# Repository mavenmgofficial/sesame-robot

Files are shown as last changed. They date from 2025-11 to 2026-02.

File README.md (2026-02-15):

# The Sesame Robot Project 
___







sesame-cover

___

**Greetings, from your new best friend.**

Sesame is an accessible Open-Source robotics project based on the ESP32 microcontroller system, with an emphasis on expression and movement. 
This project is designed for makers and engineers of all skill levels! Sesame offers a dynamic platform designed to start working with walking robots. 
To build a sesame robot, you will need basic soldering skills, $50-60 in hardware components, access to a 3D printer, and a basic understanding of Arduino IDE.

This repository contains the CAD design files, STL files, build and wiring guides, and the base/expanded firmware for the ESP32-based controller. 
There is also some included debugging firmware that may be helpful in getting your Sesame up and running.

## Features

*   **Quadruped Design:** Uses 8 servo motors (2 per leg) to achieve roughly 8 total degrees of freedom.
*   **Emotive Display:** Features a 128x64 OLED screen acting as a reactive face that syncs with movement.
*   **Fully Printable:** Designed entirely for 3D printing in PLA with minimal supports.
*   **Network Connectivity:** Connect to your WiFi network for remote control and API access.
*   **JSON API:** RESTful API for programmatic control from Python, JavaScript, and more.
*   **Conversational Faces:** Expressive emotion library with talk variants for voice assistant projects.
*   **Sesame Studio:** New animation composer software to easily create custom movements.
*   **Sesame Companion App:** Python application for voice control and advanced interactions.
*   **Serial CLI:** Control the robot and trigger animations via a Serial Command Line Interface or the web UI.
*   **Pre-programmed Emotes:** Includes animations for Walking, Waving, Dancing, Pointing, Resting, and more.

## Watch the launch video on YouTube

<a href="https://www.youtube.com/watch?v=1UDsWkcQZhc">thumb-youtube</a>

___

## Getting Started

Follow these steps to build your own Sesame Robot:

### 1. Gather Parts 
Check the **[Bill of Materials (BOM)](hardware/bom/README.md)** for a complete list of required electronics and hardware.
*   Microcontroller: Lolin S2 Mini (recommended for new builds) or ESP32-DevKitC-32E with Distro Board V1
*   Actuators: 8x MG90 Servos
*   Power: 5V 3A source (USB-C PD for S2 Mini or battery + buck for both; see BOM for the 2× 10440 Li-ion + 2× AAA holder option)

### 2. Print Parts 
Download the STLs and follow the **[Printing Guide](hardware/printing/README.md)**.
*   Designed for PLA
*   Minimal supports required

### 3. Build & Wire 
Follow the **[Build Guide](docs/build-guide/README.md)** and **[Wiring Guide](docs/wiring-guide/README.md)** to assemble the frame and connect the electronics.

### 4. Flash Firmware 
Upload the code from the **[Firmware Directory](firmware/README.md)**.
*   Requires Arduino IDE
*   Configure WiFi AP settings

### 5. Create Animations 
Use **[Sesame Studio](software/sesame-studio/README.md)** to visually design poses and sequences for your robot.

sesame-wakeup-gif

---

## Software & Firmware

### Sesame Studio
Sesame Studio is a standalone desktop application included in `software/sesame-studio/`. It allows you to:
*   Visually pose the robot using a schematic interface.
*   Generate C++ code for servo angles automatically.
*   Sequence frames into complex animations.

[**> Go to Sesame Studio**](software/sesame-studio/README.md)

sesamestudio-preview

### Sesame Companion App
The Sesame Companion App is a Python-based application that enables advanced control and interaction with your robot over your local network. It leverages the new JSON API and network mode features to provide:
*   **Voice Assistant Integration:** Control Sesame with voice commands and see real-time emotional expressions.
*   **Remote Control:** Command your robot from anywhere on your local network.
*   **Face Control:** Change expressions dynamically based on conversation or context.
*   **API Examples:** Reference implementation for building your own integrations.

The Companion App works with robots running the latest firmware with network mode enabled.

[**> Go to Sesame Companion App Repository**](https://github.com/dorianborian/sesame-companion-app)

### Firmware
The ESP32 firmware (`sesame-firmware-main.ino`) handles the kinematics, face display, and WiFi control interface.
*   **Web UI:** Control the robot from your phone via the built-in Access Point.
*   **Custom Faces:** Add your own bitmaps (guide in firmware docs).

[**> Go to Firmware Docs**](firmware/README.md)

firmware-preview

---

## Contributing

This robot is a platform for building new features, cosmetics, tools, and ideas. Since the current firmware is a basic implementation, pull requests are very welcome for:
*   Kinematics improvements
*   New animations
*   Improved Web UI/UX
*   Sensor integration (Ultrasonic, Gyro, etc.)

I would also love to see forks of this project with new hardware, software, faces, etc. Be sure to send me a message if you end up building one, and I might feature you on my website or channel!
  
---

## Sesame Complete Build Kit Pre-orders available!
I am excited to announce that, after popular demand, Sesame Complete Build Kits are now available for pre-order! 

That's right, your little robot companion just got even easier to build. Each kit includes all the components you need to build a full Sesame Robot. With the included detailed instructions, guides, and resources, this kit is perfect for both seasoned Makers and beginners. Click the image below to learn more.

<a href="https://www.doriantodd.com/sesame/kit">kits-availible</a>

---

*Created by [Dorian Todd](https://www.doriantodd.com/). Need help with your Sesame Robot? Send me a message on Discord, my username is "starphee"*

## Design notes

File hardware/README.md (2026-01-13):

# Hardware

All mechanical and electrical source files for the Sesame Robot live here. The hardware stack supports two build paths:

- **Hand-wired / S2 Mini build** for simple protoboard construction.
- **Custom Sesame Distro Board build** for a cleaner ESP32-DevKitC-32E stackup.

Use the sections below to jump to the files that match the version you are assembling.

## Directory Guide

| Folder | What you will find |
| --- | --- |
| [bom](bom/README.md) | Full bill of materials covering both wiring approaches, plus power budget notes and links back to the build tutorial. Start here to gather every component before printing or soldering. |
| [cad](cad/README.md) | Parametric STEP and Fusion 360 source models for every printed part. Great for remixing joint geometry or adapting the shell—just note the caution about features that may not translate across CAD packages. |
| [pcb](pcb/README.md) | Sesame Distro Board schematics, layout renders, and the `Gerber_Sesame-Distro-Board_PCB_Sesame-Distro-Board_V1.zip` archive you can upload to PCBway (ordering steps included). |
| [printing](printing/README.md) | Practical PLA print settings, support callouts, and image references for joint orientation and the top cover’s manual supports. |

## Getting Started

1. **Decide on a wiring strategy.** Review the comparison section in [docs/wiring-guide/README.md](../docs/wiring-guide/README.md) to choose between the protoboard and custom PCB routes.
2. **Print the shell and joints.** Follow the presets in [printing/README.md](printing/README.md) to prep the 3D files from `hardware/printing/stl`.
3. **Source electronics.** Use the line-by-line list in [bom/README.md](bom/README.md) and verify your power supply meets the 5V/3A requirement.
4. **Assemble electronics.** Reference either the hand-wiring steps or the distro-board guide plus the wiring diagrams in `docs/wiring-guide/`.

> [!TIP]
> Keep photos of your wiring progress. They are invaluable for troubleshooting later and help when sharing build notes with the community.

## Supporting Documents

- [docs/build-guide/README.md](../docs/build-guide/README.md) for end-to-end assembly sequencing.
- [docs/wiring-guide/README.md](../docs/wiring-guide/README.md) for wiring diagrams, safety notes, and packing tips.

Improvements, remixes, and test reports are welcome, file issues or PRs with any updates you discover while building. <3

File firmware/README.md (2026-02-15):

# Sesame Robot Firmware

This document provides technical information on the firmware architecture, control logic, and hardware abstraction layers used in the Sesame Robot.

>[!NOTE]
> The firmware is now organized into a modular structure with a main entry point and specialized header files for bitmaps, movement, and web assets. This makes customization much easier and the codebase cleaner.

## Table of Contents

- [How to Flash the Firmware](#how-to-flash-the-firmware)
- [Network Configuration](#network-configuration--connectivity)
- [API Reference](#api-reference)
  - [Legacy Web Endpoints](#legacy-web-endpoints)
  - [JSON API](#json-api-recommended-for-network-clients)
  - [Python Examples](#python-api-example)
  - [JavaScript Examples](#nodejsjavascript-example)
- [Advanced Integration Examples](#advanced-integration-examples)
  - [Voice Assistant Integration](#voice-assistant-integration)
  - [Home Automation](#home-automation-integration)
- [Idle Animation System](#idle-animation-system)
- [Firmware Architecture](#firmware-architecture)
- [Technical Implementation](#technical-implementation-overview)
- [Asset Pipeline & Face Customization](#asset-pipeline--face-customization)
- [Hardware Abstraction Layer](#hardware-abstraction-layer-hal)

## How to Flash the Firmware

### Prerequisites
1. **Arduino IDE** (version 2.0 or higher recommended)
2. **ESP32 Board Support**: Install via Arduino IDE's Board Manager
   - Open Arduino IDE
   - Go to **File → Preferences**
   - Add to "Additional Board Manager URLs": `https://raw.githubusercontent.com/espressif/arduino-esp32/gh-pages/package_esp32_index.json`
   - Go to **Tools → Board → Boards Manager**
   - Search for "ESP32" and install "ESP32 by Espressif Systems" (v2.0.0 or higher)
3. **Required Libraries** (install via Library Manager):
   - `ESP32Servo`
   - `Adafruit SSD1306`
   - `Adafruit GFX Library`

### Flashing Steps
1. **Connect your board** via USB to your computer
2. **Open the firmware**:
   - Open [sesame-firmware-main.ino](sesame-firmware-main.ino) in Arduino IDE
   - Make sure you have it in a folder with the same name.
   - Also include all of the .h header files.
3. **Select your board**:
   - Go to **Tools → Board**
   - For Lolin S2 Mini: Select "LOLIN S2 Mini"
   - For Sesame Distro Board V1: Select "ESP32 Dev Module"
4. **Configure board settings** (if using Lolin S2 Mini):
   - **Upload Speed**: 921600
   - **USB CDC On Boot**: "Enabled"
   - **Partition Scheme**: "Default 4MB with spiffs"
5. **Select the correct port**:
   - Go to **Tools → Port** and select your ESP32's COM port
6. **Choose your board configuration** in the code:
   - Open [sesame-firmware-main.ino](sesame-firmware-main.ino)
   - Find the pin configuration section (around line 55-65)
   - **If you built with the Lolin S2 Mini:** Uncomment the S2 Mini `servoPins` array and `I2C_SDA`/`I2C_SCL` defines. Comment out the Distro Board section.
   - **If you built with the Distro Board V1 and ESP32-DevKitC-32E:** Uncomment the Distro Board `servoPins` array and `I2C_SDA`/`I2C_SCL` defines. Comment out the S2 Mini section.
7. **(Optional) Configure network mode**:
   - If you want the robot to connect to your WiFi network (for API access and remote control), edit the network configuration section (around line 17-22):
   ```cpp
   #define NETWORK_SSID "YourNetworkName"  // Your WiFi network name
   #define NETWORK_PASS "YourPassword"     // Your WiFi password
   #define ENABLE_NETWORK_MODE true        // Set to true to enable
   ```
   - Leave `ENABLE_NETWORK_MODE false` to use Access Point mode only
8. **Upload the firmware**:
   - Click the **Upload** button (→) in Arduino IDE
   - Wait for compilation and upload to complete
9. **Test the connection**:
   - Open Serial Monitor (**Tools → Serial Monitor**, set baud rate to 115200)
   - Reset the board - you should see startup messages and network information
   - The serial monitor provides individual motor control for testing and troubleshooting
   - **If using AP mode only**: Connect to the "Sesame-Controller-BETA" WiFi network (password: `12345678`) and navigate to any website
   - **If using network mode**: Look for the "Connected to network!" message in Serial Monitor, then access via `http://sesame-robot.local` or the displayed IP address

### Troubleshooting
- **Upload fails**: Try holding the BOOT button while uploading, or try a different USB cable
- **Port not found**: Install the appropriate USB drivers (CP210x for S2 Mini, CH340 for some ESP32 boards)
- **Compilation errors**: Verify all required libraries are installed
- **Robot not moving**: Check power supply and servo connections; increase `motorCurrentDelay` in web settings if brownouts occur
- **Can't connect to network**: 
  - Verify `ENABLE_NETWORK_MODE` is set to `true` and SSID/password are correct
  - Check Serial Monitor for connection status - look for "Connected to network!" or error messages
  - Ensure your WiFi network is 2.4GHz (ESP32 does not support 5GHz)
  - Try increasing the connection timeout in the code (currently 10 seconds / 20 attempts)
- **mDNS hostname not resolving**:
  - On Windows, install [Bonjour Print Services](https://support.apple.com/kb/DL999)
  - On Linux, ensure `avahi-daemon` is installed and running
  - Try accessing via IP address instead (check Serial Monitor for the assigned IP)
  - Some routers block mDNS traffic - check router settings or use IP address
- **API commands not working**:
  - Ensure you're sending POST requests to `/api/command` (not GET)
  - Verify `Content-Type: application/json` header is set
  - Check Serial Monitor for error messages and parsed command output
  - Test with a simple cURL command first to verify connectivity

## Firmware Architecture

The firmware is split into several key files to keep the logic organized and assets easy to manage:

- **[sesame-firmware-main.ino](sesame-firmware-main.ino)**: The main entry point containing the `setup()`, `loop()`, core system logic, network configuration, and API endpoints.
- **[face-bitmaps.h](face-bitmaps.h)**: A dedicated header for OLED face macros and raw bitmap data. Now includes extensive conversational faces for voice assistant integration.
- **[movement-sequences.h](movement-sequences.h)**: Definitions for all procedural movement and pose animations.
- **[captive-portal.h](captive-portal.h)**: Contains the HTML, CSS, and JS for the web-based remote control interface.

## Technical Implementation Overview

The firmware is built on the Arduino-ESP32 framework. Currently the firmware is running on a single-core event loop, and hardware-based PWM timers for precise motor control.

### PWM & Servo Kinematics
- **Timer Allocation**: The firmware uses `ESP32PWM::allocateTimer(n)` to reserve hardware timers 0-3. This prevents conflicts with other peripherals and ensuring high-resolution PWM signals (50Hz frequency). Due to the limited number of timers, you may experience network errors upon adding additional devices or calls to the firmware. For example, in a modded version of the robot, I tried adding two ESCs and their servo controll to the code, and the CPU ran out of internal timers and caused the captive portal to die. If you are experiencing network errors with your custom firmware, check the timer allocation.
- **Pulse Width Mapping**: Leg servos are mapped from degrees (0-180) to microseconds (732us to 2929us). This range is set to the maximum travel on most hobby servos with a 180 degree limit, but can be edited in the `servos[i].attach()` calls. If you are using motors with a larger range of motion, like 270 degree servos, you need to set the PWM mapping to a different length of microseconds. For 270 degree servos specifically I found (833us to 2167us) works.
- **Staggered Activation**: To prevent VCC rail collapse (brownout) caused by simultaneous inductive loads, the `setServoAngle` helper introduces a mandatory `motorCurrentDelay` (default 20ms) between sequential pulses. This delay should be tweaked to your power setup. If you have a strong dedicated power supply you can try setting it to zero. It can also be changed while running through the AP controller settings menu.

### Communication & Networking Stack
- **Dual-Mode WiFi**: The ESP32 can simultaneously operate in both Access Point mode (for direct connections) and Station mode (connected to an existing network) using `WiFi.mode(WIFI_AP_STA)`.
- **SoftAP & Captive Portal**: The ESP32 initializes an Access Point using `WiFi.softAP()`. A `DNSServer` listens on UDP Port 53, using a wildcard "*" redirect to map all DNS queries to the internal gateway (`192.168.4.1`).
- **mDNS Service Discovery**: The firmware broadcasts `sesame-robot.local` via Multicast DNS (mDNS) using the `ESPmDNS` library, allowing network discovery without hardcoded IP addresses.
- **RESTful API Surface**: The `WebServer` handles both legacy URL-parameter endpoints and modern JSON-based API:
  - `/cmd?go=[dir]`: Legacy movement control
  - `/cmd?pose=[name]`: Legacy pose triggers
  - `/api/status`: JSON status endpoint (GET)
  - `/api/command`: JSON command endpoint (POST) - supports face-only updates and combined face+movement commands
  - `/getSettings` / `/setSettings`: Parameter configuration
- **Face-Only Command Support**: The `/api/command` endpoint intelligently detects face-only requests (no `command` field) and updates the display without triggering movement animations.
- **Non-Blocking Control Flow**: Instead of `delay()`, the firmware uses a custom `pressingCheck(String cmd, int ms)` function. This function polls `server.handleClient()` and `dnsServer.processNextRequest()` during animation frames, allowing for real-time interruptibility (e.g., immediate stop on button release). This pressingCheck protocol can be used for motion commands like walking to play each motion only when the button is held.

### Display & Graphics Subsystem
- **I2C Bus Hardware**: Utilizes the ESP32's hardware I2C controller at 400kHz (Fast Mode) for minimal latency when pushing full-frame buffers to the SSD1306 display.
- **Memory Management (`PROGMEM`)**: Large 128x64 bitmap arrays (1024 bytes per frame) are stored in Flash memory using the `PROGMEM` attribute.
- **Macro-Based Asset Management**: The firmware uses a `FACE_LIST` macro in [face-bitmaps.h](face-bitmaps.h) to automatically register and handle new faces, reducing the boilerplate required when adding animations.
- **Rendering Pipeline**: The `updateAnimatedFace()` function manages frame rates and sequence looping outside of the main movement logic to ensure smooth visual feedback even during complex movements.
- **Dynamic WiFi Info Overlay**: The `updateWifiInfoScroll()` function composites scrolling connection information over the face bitmap during the first 30 seconds of operation (before first input), drawing the face as background with a black bar and white text overlay for readability.
- **Idle Animation System**: Implements realistic idle behavior with randomized blinking (including double-blinks) and boomerang face animations, triggered automatically when no input is detected.

## Prerequisites & Development Environment

- **Board Support**: ESP32 by Espressif Systems (v2.0.0+ recommended). Lolin S2 Mini and ESP32-WROOM32 DevKitC are best supported.
- **Libraries**:
  - `ESP32Servo`: Low-level PWM timer management.
  - `Adafruit_SSD1306` & `Adafruit_GFX`: Buffer-based OLED rendering.
  - `ESPmDNS`: mDNS service discovery (included with ESP32 board support).
  - `DNSServer`: Captive portal DNS redirection (included with ESP32 board support).
  - `WebServer`: HTTP server implementation (included with ESP32 board support).
- **Tooling**: Arduino IDE 2.0+ recommended.

## Network Configuration & Connectivity

The firmware now supports **dual-mode WiFi operation**, allowing the robot to simultaneously act as an Access Point (for direct connections) and connect to your existing WiFi network (for integration with other devices and remote control).

### Access Point Mode (Default)
By default, the robot creates its own WiFi network:
- **SSID**: `Sesame-Controller-BETA`
- **Password**: `12345678`
- **IP Address**: `192.168.4.1`

Connect to this network and navigate to any website to access the captive portal control interface.

### Network Mode (Optional)
To connect the robot to your home or office WiFi network:

1. **Enable Network Mode** in [sesame-firmware-main.ino](sesame-firmware-main.ino):
   ```cpp
   #define NETWORK_SSID "YourNetworkName"  // Your WiFi network name
   #define NETWORK_PASS "YourPassword"     // Your WiFi password
   #define ENABLE_NETWORK_MODE true        // Set to true to enable
   ```

2. **Flash the updated firmware** to your robot.

3. **Access via multiple methods**:
   - **mDNS Hostname**: `http://sesame-robot.local` (works on most devices)
   - **Network IP**: Check Serial Monitor at 115200 baud for the assigned IP address
   - **Still accessible via AP**: The robot maintains its Access Point even when connected to your network

### mDNS Discovery
The firmware includes an mDNS responder that broadcasts the hostname `sesame-robot.local` on your local network. This allows you to access the robot without knowing its IP address:

```bash
# Access from browser
http://sesame-robot.local

# Ping test
ping sesame-robot.local
```

**Note**: mDNS works natively on:
- macOS and iOS devices
- Linux with Avahi installed
- Windows 10+ (may require Bonjour service)

### Security Considerations

The firmware is designed for local network use and does not include authentication by default. When enabling network mode:

- **Local Network Only**: The robot responds to requests from any device on your network. Do not expose it to the internet without proper security measures.
- **No HTTPS**: Communication is unencrypted HTTP. Avoid transmitting sensitive data through the robot's API.
- **Access Point Password**: The default AP password is `12345678`. For production use, change `AP_PASS` in the firmware to a stronger password.
- **Trusted Networks**: Only connect your robot to trusted WiFi networks.

For enhanced security:
1. Change the default AP password to a strong, unique password
2. Use network segmentation (IoT VLAN) to isolate the robot from critical devices
3. Implement firewall rules to restrict access to specific IP addresses
4. Consider adding authentication headers in a custom firmware fork for production deployments

### WiFi Information Display
The robot's OLED screen now features an intelligent WiFi info system:
- **First 30 seconds**: If no input is received, WiFi connection information scrolls across the top of the display
- **After first input**: WiFi info disappears to show only faces
- **Dual-mode info**: When connected to both AP and network, displays both connection details

The scrolling text includes:
- Access Point SSID and IP
- Network name and IP (if connected)
- mDNS hostname
- Captive portal instructions

## API Reference

The firmware exposes both legacy web endpoints and a modern JSON-based API for programmatic control.

### Legacy Web Endpoints

These endpoints use URL parameters and are primarily used by the web interface:

#### Movement Control
```http
GET /cmd?go=forward
GET /cmd?go=backward
GET /cmd?go=left
GET /cmd?go=right
GET /cmd?stop
```

#### Pose Control
```http
GET /cmd?pose=wave
GET /cmd?pose=dance
GET /cmd?pose=rest
GET /cmd?pose=stand
# ... (see movement-sequences.h for all available poses)
```

#### Individual Motor Control
```http
GET /cmd?motor=1&value=90
# motor: 1-8 (motor number)
# value: 0-180 (angle in degrees)
```

#### Settings Management
```http
GET /getSettings
# Returns: {"frameDelay":100,"walkCycles":10,"motorCurrentDelay":20,"faceFps":8}

GET /setSettings?frameDelay=120&walkCycles=15&motorCurrentDelay=25&faceFps=10
```

### JSON API (Recommended for Network Clients)

The JSON API is designed for programmatic control from external devices, Python scripts, and IoT integrations.

#### Get Robot Status
```http
GET /api/status
```

**Response:**
```json
{
  "currentCommand": "forward",
  "currentFace": "walk",
  "networkConnected": true,
  "apIP": "192.168.4.1",
  "networkIP": "192.168.1.100"
}
```

#### Send Commands
```http
POST /api/command
Content-Type: application/json

{
  "command": "forward",
  "face": "walk"
}
```

**Response:**
```json
{
  "status": "ok",
  "message": "Command executed"
}
```

#### Face-Only Updates
Send a face change without triggering movement:

```http
POST /api/command
Content-Type: application/json

{
  "face": "happy"
}
```

**Response:**
```json
{
  "status": "ok",
  "message": "Face updated"
}
```

#### Stop Command
```http
POST /api/command
Content-Type: application/json

{
  "command": "stop"
}
```

### Available Commands

**Movement Commands:**
- `forward`, `backward`, `left`, `right` - Continuous movement (loops until stopped)
- `stop` - Immediately stop current movement

**Pose Commands (one-shot animations):**
- `rest`, `stand`, `wave`, `dance`, `swim`, `point`
- `pushup`, `bow`, `cute`, `freaky`, `worm`, `shake`
- `shrug`, `dead`, `crab`

**Available Faces:**
- Movement faces: `walk`, `rest`, `stand`, `dance`, `wave`, etc.
- Conversational faces: `happy`, `sad`, `angry`, `surprised`, `sleepy`, `love`, `excited`, `confused`, `thinking`
- Talk variants: `talk_happy`, `talk_sad`, `talk_angry`, etc.
- Special: `idle`, `idle_blink`, `default`

### Python API Example

```python
import requests
import time

# Robot IP or hostname
robot_url = "http://sesame-robot.local"

# Get status
response = requests.get(f"{robot_url}/api/status")
status = response.json()
print(f"Current face: {status['currentFace']}")

# Make robot wave and show happy face
requests.post(f"{robot_url}/api/command", json={
    "command": "wave",
    "face": "happy"
})

time.sleep(3)

# Just change face without moving
requests.post(f"{robot_url}/api/command", json={
    "face": "excited"
})

# Stop movement
requests.post(f"{robot_url}/api/command", json={
    "command": "stop"
})
```

### cURL Examples

```bash
# Get robot status
curl http://sesame-robot.local/api/status

# Make robot dance
curl -X POST http://sesame-robot.local/api/command \
  -H "Content-Type: application/json" \
  -d '{"command":"dance","face":"dance"}'

# Change face only
curl -X POST http://sesame-robot.local/api/command \
  -H "Content-Type: application/json" \
  -d '{"face":"happy"}'

# Stop movement
curl -X POST http://sesame-robot.local/api/command \
  -H "Content-Type: application/json" \
  -d '{"command":"stop"}'
```

### Node.js/JavaScript Example

```javascript
const robotURL = 'http://sesame-robot.local';

// Get status
fetch(`${robotURL}/api/status`)
  .then(res => res.json())
  .then(data => console.log('Robot status:', data));

// Send command
fetch(`${robotURL}/api/command`, {
  method: 'POST',
  headers: {'Content-Type': 'application/json'},
  body: JSON.stringify({
    command: 'wave',
    face: 'happy'
  })
})
.then(res => res.json())
.then(data => console.log('Response:', data));

// Face-only update
fetch(`${robotURL}/api/command`, {
  method: 'POST',
  headers: {'Content-Type': 'application/json'},
  body: JSON.stringify({face: 'surprised'})
})
.then(res => res.json())
.then(data => console.log('Response:', data));
```

## Advanced Integration Examples

### Voice Assistant Integration

The combination of conversational faces, the JSON API, and network mode makes the Sesame Robot perfect for voice assistant projects. Here's an example using Python with speech recognition:

```python
import requests
import speech_recognition as sr
from textblob import TextBlob
import time

robot_url = "http://sesame-robot.local"

def analyze_sentiment(text):
    """Analyze sentiment and return appropriate face"""
    blob = TextBlob(text)
    polarity = blob.sentiment.polarity
    
    if polarity > 0.5:
        return "excited"
    elif polarity > 0.2:
        return "happy"
    elif polarity < -0.5:
        return "angry"
    elif polarity < -0.2:
        return "sad"
    else:
        return "thinking"

def set_robot_face(face, talking=False):
    """Update robot's face expression"""
    if talking:
        face = f"talk_{face}"
    
    requests.post(f"{robot_url}/api/command", json={"face": face})

# Initialize speech recognition
recognizer = sr.Recognizer()

while True:
    with sr.Microphone() as source:
        print("Listening...")
        set_robot_face("idle")
        
        try:
            audio = recognizer.listen(source, timeout=5)
            set_robot_face("thinking")
            
            text = recognizer.recognize_google(audio)
            print(f"You said: {text}")
            
            # Determine emotion and show talking face
            emotion = analyze_sentiment(text)
            set_robot_face(emotion, talking=True)
            
            # Process command...
            time.sleep(2)
            
            # Return to neutral
            set_robot_face(emotion, talking=False)
            
        except sr.WaitTimeoutError:
            set_robot_face("sleepy")
        except sr.UnknownValueError:
            set_robot_face("confused")
```

### Home Automation Integration

Integrate with Home Assistant or other home automation platforms:

```python
# Home Assistant automation example
import requests

def robot_notification(message_type):
    """Display robot emotion based on notification type"""
    robot_url = "http://sesame-robot.local"
    
    emotion_map = {
        "doorbell": "surprised",
        "alarm": "angry",
        "reminder": "thinking",
        "success": "happy",
        "error": "sad"
    }
    
    face = emotion_map.get(message_type, "default")
    requests.post(f"{robot_url}/api/command", json={"face": face})
    
    # Optional: add movement
    if message_type == "doorbell":
        requests.post(f"{robot_url}/api/command", json={
            "command": "wave",
            "face": "happy"
        })
```

### WebSocket Streaming (Advanced)

For real-time control with minimal latency, you can poll the status endpoint or implement a simple state machine:

```javascript
// React/Vue.js real-time robot control
class RobotController {
  constructor(robotURL) {
    this.url = robotURL;
    this.currentFace = 'default';
  }
  
  async updateEmotion(emotion, isSpeaking) {
    const face = isSpeaking ? `talk_${emotion}` : emotion;
    
    if (face !== this.currentFace) {
      await fetch(`${this.url}/api/command`, {
        method: 'POST',
        headers: {'Content-Type': 'application/json'},
        body: JSON.stringify({face})
      });
      
      this.currentFace = face;
    }
  }
  
  async getStatus() {
    const res = await fetch(`${this.url}/api/status`);
    return await res.json();
  }
  
  async performAction(action, emotion = null) {
    const payload = {command: action};
    if (emotion) payload.face = emotion;
    
    await fetch(`${this.url}/api/command`, {
      method: 'POST',
      headers: {'Content-Type': 'application/json'},
      body: JSON.stringify(payload)
    });
  }
}

// Usage
const robot = new RobotController('http://sesame-robot.local');

// Set emotion without moving
await robot.updateEmotion('happy', false);

// Set talking face
await robot.updateEmotion('excited', true);

// Perform action with face
await robot.performAction('dance', 'excited');

// Check status
const status = await robot.getStatus();
console.log(`Robot is ${status.currentFace} and doing ${status.currentCommand}`);
```

## Idle Animation System

The firmware includes an intelligent idle animation system that activates automatically:

### Behavior
- **Activation**: When the robot has received no commands for a period, it enters idle mode
- **Idle Face**: Displays a gentle "breathing" animation using the `idle` face in `FACE_ANIM_BOOMERANG` mode
- **Blinking**: Randomly triggers blink animations (3-7 second intervals)
- **Double Blinks**: 30% chance of a double blink for realistic behavior
- **Exit**: Any movement command or input immediately exits idle mode

### Technical Implementation
The idle system uses:
- `enterIdle()` - Activates idle face with boomerang animation
- `exitIdle()` - Returns to normal operation
- `updateIdleBlink()` - Manages random blink timing and double-blink logic
- `scheduleNextIdleBlink()` - Randomizes blink intervals for natural appearance

To customize idle behavior, modify the timing values in [sesame-firmware-main.ino](sesame-firmware-main.ino):
```cpp
scheduleNextIdleBlink(3000, 7000);  // Min and max ms between blinks
```

## Asset Pipeline & Face Customization

The firmware includes an intelligent idle animation system that activates automatically:

### Behavior
- **Activation**: When the robot has received no commands for a period, it enters idle mode
- **Idle Face**: Displays a gentle "breathing" animation using the `idle` face in `FACE_ANIM_BOOMERANG` mode
- **Blinking**: Randomly triggers blink animations (3-7 second intervals)
- **Double Blinks**: 30% chance of a double blink for realistic behavior
- **Exit**: Any movement command or input immediately exits idle mode

### Technical Implementation
The idle system uses:
- `enterIdle()` - Activates idle face with boomerang animation
- `exitIdle()` - Returns to normal operation
- `updateIdleBlink()` - Manages random blink timing and double-blink logic
- `scheduleNextIdleBlink()` - Randomizes blink intervals for natural appearance

To customize idle behavior, modify the timing values in [sesame-firmware-main.ino](sesame-firmware-main.ino):
```cpp
scheduleNextIdleBlink(3000, 7000);  // Min and max ms between blinks
```

## Hardware Abstraction Layer (HAL)

The firmware abstracts pin definitions via the `servoPins` array. The default configuration is optimized for the **Sesame Distro Board** and **Lolin S2 Mini**, but is easily portable to any ESP32 with WiFi capability (e.g., S3, C3, or DevKit V1).

### Pin Configuration Tables

#### Lolin S2 Mini (ESP32-S2)

| Motor/Component | Array Index | GPIO Pin | Notes |
|---|---|---|---|
| Motor 0 | 0 | 1 | R1 |
| Motor 1 | 1 | 2 | R2 |
| Motor 2 | 2 | 4 | L1 |
| Motor 3 | 3 | 6 | L2 |
| Motor 4 | 4 | 8 | R4 |
| Motor 5 | 5 | 10 | R3 |
| Motor 6 | 6 | 13 | L3 |
| Motor 7 | 7 | 14 | L4 |
| **I2C SDA** | - | **33** | SSD1306 Data (Hardware I2C) |
| **I2C SCL** | - | **35** | SSD1306 Clock (Hardware I2C) |

#### Sesame Distro Board (ESP32-WROOM32)

| Motor/Component | Array Index | GPIO Pin | Notes |
|---|---|---|---|
| Motor 0 | 0 | 15 | R1 |
| Motor 1 | 1 | 2 | R2 |
| Motor 2 | 2 | 23 | L1 |
| Motor 3 | 3 | 19 | L2 |
| Motor 4 | 4 | 4 | R4 |
| Motor 5 | 5 | 16 | R3 |
| Motor 6 | 6 | 17 | L3 |
| Motor 7 | 7 | 18 | L4 |
| **I2C SDA** | - | **21** | SSD1306 Data (Hardware I2C) |
| **I2C SCL** | - | **22** | SSD1306 Clock (Hardware I2C) |

### Porting to Other ESP32 Variants

To port this to a different ESP32 variant, modify the `servoPins` and `I2C_` defines in the header of [sesame-firmware-main.ino](sesame-firmware-main.ino). Ensure the chosen pins are PWM-capable and not "input-only".

## Asset Pipeline & Face Customization

To maintain a clean main source file and optimize performance, face bitmaps are decoupled from the primary logic. Faces are managed in [face-bitmaps.h](face-bitmaps.h) using a "Single Source of Truth" macro system.

### Face Library

The firmware includes an extensive library of faces organized into three categories:

#### Movement Faces
Synchronized with physical poses and animations:
- `walk`, `rest`, `stand`, `swim`, `dance`, `wave`, `point`
- `pushup`, `bow`, `cute`, `freaky`, `worm`, `shake`, `shrug`
- `dead`, `crab`, `idle`, `idle_blink`

#### Conversational Faces
Designed for expressive communication and voice assistant integration:
- **Base emotions**: `happy`, `sad`, `angry`, `surprised`, `sleepy`, `love`, `excited`, `confused`, `thinking`
- **Talk variants**: `talk_happy`, `talk_sad`, `talk_angry`, `talk_surprised`, `talk_sleepy`, `talk_love`, `talk_excited`, `talk_confused`, `talk_thinking`

The "talk_" variants feature open mouths for lip-sync and animated speech. These faces are perfect for:
- Voice assistant projects (Alexa, Google Assistant, custom TTS)
- Chatbot interfaces controlled via the JSON API
- Interactive storytelling and educational applications
- Remote-controlled performances

#### Special Faces
- `default` - The startup/fallback face
- `idle` - Gentle breathing animation for idle state
- `idle_blink` - Blink animation triggered randomly during idle

### Adding Custom Faces

### Workflow:
1.  **Image Creation**: Find faces using Kaomoji or [Emojicombos](https://emojicombos.com/kaomoji). Create a `128x64` image in a tool like [jsPaint](https://jspaint.app/).
2.  **Bitmap Conversion**: Use [image2cpp](https://javl.github.io/image2cpp/) with `Horizontal` scaling, `128x64` resolution, and `Arduino Code` output.
3.  **Registration**:
    -   Add your face name to the `FACE_LIST` macro in [face-bitmaps.h](face-bitmaps.h).
    -   Paste the generated C array into [face-bitmaps.h](face-bitmaps.h) right after the last bitmap in the list.
    -   (Optional) For animations, add numbered suffixes (e.g., `_1`, `_2`) and register the FPS in the `faceFpsEntries` in [sesame-firmware-main.ino](sesame-firmware-main.ino).

### Animating Faces
For an animation to be recognized by the `MAKE_FACE_FRAMES` macro, your array names in [face-bitmaps.h](face-bitmaps.h) must follow a strict naming convention:
- **Root Frame**: `epd_bitmap_myface` (This is required and acts as frame 0).
- **Subsequent Frames**: `epd_bitmap_myface_1`, `epd_bitmap_myface_2`, etc.
- **Limit**: The default system supports up to 6 frames per face (Root + 5 numbered frames).
- **Animation Modes**: Animations can be configured to play as a `LOOP` (restarts at frame 0), `ONCE` (stops on the final frame), or `BOOMERANG` (plays forward then reverses). These modes are typically defined in [movement-sequences.h](movement-sequences.h) when triggerring a pose.

### Macro System
The `FACE_LIST` macro uses X-Macros to automatically generate variable declarations and registration objects:
```cpp
#define FACE_LIST \
    X(walk) \
    X(rest) \
    X(my_new_face) // Just add this line!
```
This eliminates the need to manually update multiple switch statements or arrays when adding new assets.

## Execution & Deployment

1.  **Toolchain**: Configure your IDE for `ESP32 Dev Module` or `Lolin S2 Mini`.
2.  **Calibration**: Use the Serial Monitor (115200) to send manual step commands (e.g., `rn wf`).
3.  **Power Management**: If the robot brownouts during movement, increase `motorCurrentDelay` in the web settings to further stagger servo bursts.

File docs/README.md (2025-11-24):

# Documentation

Documentation for the Sesame Robot project.

- **assembly/** - Assembly instructions
- **build-guide/** - Build guide with photos
- **images/** - Photos and diagrams
- **datasheets/** - Component datasheets

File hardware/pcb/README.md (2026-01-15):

# PCB Schematics

Electronic schematics and wiring diagrams for the Sesame Distro Board, a custom PCB just for the Sesame Robot Project. The distro boar pairs with the ESP32-DevKitC-32E.

**PCBway Sponsorship**

This project was sponsored by [PCBway](https://www.pcbway.com/), who manufactured the custom distro boards. PCBway offers high-quality PCB fabrication services with fast turnaround times and excellent customer support. You can order your own Sesame Distro Boards by uploading the Gerber files (found in the hardware section) to their website.

If you're building your own Sesame Robot, PCBway is a great option for getting professional-quality distro boards manufactured at reasonable prices.

pcbs-from-pcbway

## Board Schematic:

Schematic_Sesame-Distro-Board

### PCB Layout:
SDB-Layout

## How to order one:

1. Download the Gerber archive `Gerber_Sesame-Distro-Board_PCB_Sesame-Distro-Board_V1.zip` from this directory.
2. Upload that zip file to PCBway as the project Gerber bundle and confirm the board thickness and finish match the Sesame Distro Board requirements.
3. Double-check the provided drill, solder mask, and silkscreen layers in the preview before placing the order to ensure the traces and cutouts stay consistent with the schematic.
4. Specify the desired quantity and shipping options, then submit the order to receive professionally fabricated Sesame Distro Boards.

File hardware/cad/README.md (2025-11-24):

# CAD Files

3D CAD models and STL files for 3D printing the Sesame Robot body.

Print with PLA/PLA+ at 15-20% infill with minimal supports.

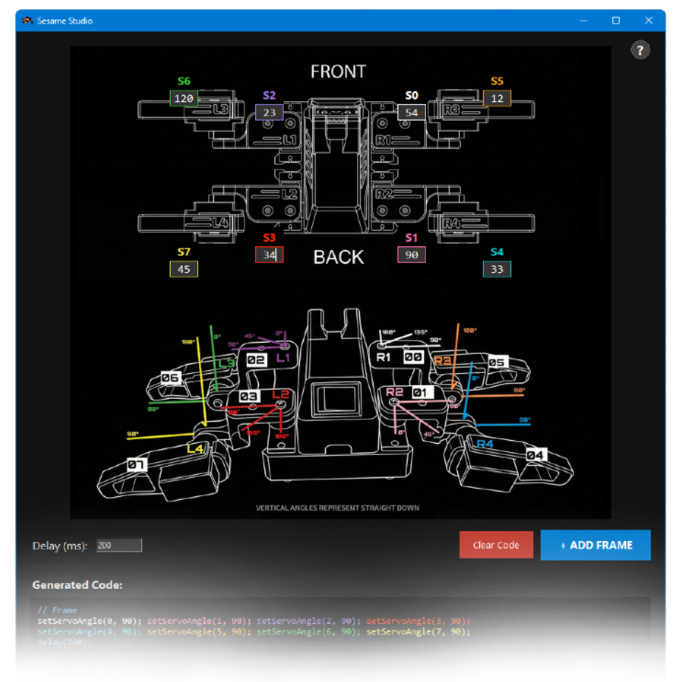
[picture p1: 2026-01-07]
software/sesame-studio/assets/sesamestudio-preview.png

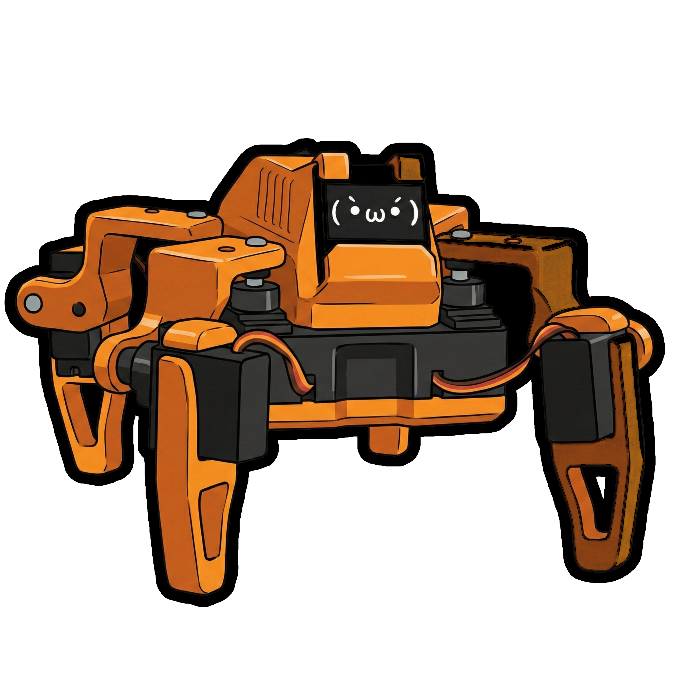
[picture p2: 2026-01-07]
software/sesame-studio/assets/sesame-sticker2.png

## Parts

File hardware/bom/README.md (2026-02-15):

# Bill of Materials

Every part required to assemble Sesame is cataloged here. Pick the wiring strategy that fits your parts bin, then follow the build flow in [docs/build-guide/README.md](../../docs/build-guide/README.md).

> [!NOTE]
> Amazon links below point to representative search results so you can choose local suppliers or equivalent listings. Pricing and availability change frequently. If you don't mind waiting shipping times you can also order direct from manufacturer for much lower rates.

## Core Electronics (Both Builds)

| Item | Qty | Notes | Amazon |
| --- | --- | --- | --- |
| MG90S all-metal micro servos | 8 (buy 10 for spares) | Primary hip/leg actuators; includes servo horns but keep extras | [link](https://www.amazon.com/s?k=mg90s+metal+gear+servo+pack+of+8) |
| 0.96" SSD1306 I2C OLED | 1 | 128x64 display that slides into the top cover slot | [link](https://www.amazon.com/s?k=0.96%22+I2C+OLED+SSD1306) |
| USB-C data/power cable | 1 | Needs to carry 5V/3A for flashing and tethered mode | [link](https://www.amazon.com/s?k=usb+c+cable+60w) |
| Rocker power switch (KDC1, panel mount) | 1 | Snaps into the top cover cutout | [link](https://www.amazon.com/s?k=kdc1+mini+rocker+switch+2+pin) |
| 22AWG silicone wire kit | 1 | Power/ground bus lines | [link](https://www.amazon.com/s?k=22awg+silicone+wire+kit) |
| 30AWG silicone wire kit | 1 | Signal leads and dense harnessing | [link](https://www.amazon.com/s?k=30awg+silicone+wire) |
| Heat-shrink assortment | 1 | Insulate OLED, switch, and battery joints | [link](https://www.amazon.com/s?k=heat+shrink+tubing+kit) |
| Small zip ties | 1 pack | Bundling wires inside the frame | [link](https://www.amazon.com/s?k=mini+zip+ties) |

## Wiring Option A – S2 Mini / Hand-Wired Harness

| Item | Qty | Notes | Amazon |
| --- | --- | --- | --- |
| Lolin/WeMos ESP32-S2 Mini | 1 | Native USB-C, fits on perfboard for the hand-wired build | [link](https://www.amazon.com/s?k=esp32+s2+mini) |
| Small protoboard (approx. 5×7 cm) | 1 | Hosts the header matrix and rails | [link](https://www.amazon.com/s?k=prototype+perfboard) |
| 3-pin male headers | 8 | Build the servo breakout; match spacing to MG90 plugs | [link](https://www.amazon.com/s?k=pin+header+strip) |
| Buck converter (5–12 V in to stable 5V/3A out) | 1 | Powers motors + MCU when using batteries | [link](https://www.amazon.com/s?k=3a+dc+dc+buck+converter+module) |

## Wiring Option B – Sesame Distro Board V2 (Included in Build Kits)

> [!NOTE]
> If you purchased a Sesame Build Kit, your V2 Distro Board is already assembled, pre-flashed, and included. You don't need to order these parts separately.

| Item | Qty | Notes | Amazon |
| --- | --- | --- | --- |
| Sesame Distro Board V2 PCB | 1 | Fully SMD design. Order with PCBway assembly service or attempt advanced hand soldering. See [ordering guide](/hardware/pcb/README.md) | [link](/hardware/pcb/README.md) |

## Wiring Option C – Sesame Distro Board V1 / ESP32-DevKitC-32E (Legacy)

> [!CAUTION]
> V1 is now phased out but still supported. Only choose this if you already have a V1 board.

| Item | Qty | Notes | Amazon |
| --- | --- | --- | --- |
| ESP32-DevKitC-32E (ESP32-WROOM-32) | 1 | Base board the Distro Board V1 stacks on. This one is very tricky because its a very specific board. You can use the 32E with the floating pcb antenna OR you can use the 32U but you have to route an antenna inside. | [link](https://www.amazon.com/s?k=ESP32+DevKitC+32) |
| Sesame Distro Board V1 PCB | 1 | Order `Gerber_Sesame-Distro-Board_PCB_Sesame-Distro-Board_V1.zip` via PCBway | [link](/hardware/pcb/README.md) |
| 5V buck converter (same spec as above) | 1 | Mounts on the distro board pads | [link](https://www.amazon.com/s?k=3a+dc+dc+buck+converter+module) |
| 1000 µF electrolytic capacitor | 1 | Smooths output voltage on buck converter; 10V+ rating recommended | [link](https://www.amazon.com/s?k=1000uf+electrolytic+capacitor) |
| 4-pin JST-XH or PH header | 1 | Optional external connector footprint on PCB | [link](https://www.amazon.com/s?k=jst+xh+4+pin+kit) |
| 2-pin screw terminal (2.54 mm pitch) | 1 | Optional battery input on PCB | [link](https://www.amazon.com/s?k=2+pin+screw+terminal+block+2.54mm+pitch) |
| M2.5 × 5 mm male-female standoffs | 4 | Elevate the PCB over the DevKit mounting holes | [link](https://www.amazon.com/s?k=m2.5+male+female+standoff+5mm) |

## Power Sources & Connectors

| Item | Qty | Notes | Amazon |
| --- | --- | --- | --- |
| 3S 450 mAh LiPo with XT30 | 1 | Recommended wireless pack; ensure high-discharge rating | [link](https://www.amazon.com/s?k=3s+450mah+lipo+xt30) |
| 2× AAA holder | 1 set | 2S pack using AAA size Li-Ion Batteries (~7.4 V nominal) that fits the chassis battery slot; use a buck converter | [link](https://www.amazon.com/s?k=2x+aaa+battery+holder) |
| 10440 Li-ion cells (350–400 mAh typical) | 2 | Standard 10×44 mm Li-ion cells; buy spares | [link](https://www.amazon.com/s?k=10440+li-ion+cell+350mah) |
| 2-slot 10440 Li-ion charger | 1 | Charge cells outside the holder; avoid in-holder charging unless the holder is designed for it | [link](https://www.amazon.com/s?k=10440+li-ion+charger+2+slot) |
| XT30 female pigtail | 1 | Interface battery to switch/PCB without cutting stock leads | [link](https://www.amazon.com/s?k=xt30+female+pigtail) |

## Fasteners & Mechanical Hardware

| Item | Qty | Usage | Amazon |
| --- | --- | --- | --- |
| M2 × 5 mm self-threading screws | ~40 | All plastic joints, OLED retention, motor mounts, and covers (Can just get a variety pack) | [link](https://www.amazon.com/s?k=m2+self+tapping+screws+kit) |
| M2.5 × 5mm machine screws | 10 | Servo horn attachment to servo shafts only. Included servo horn screws are usually too short. | [link](https://www.amazon.com/s?k=m2+machine+screw+kit) |

## 3D Printed Parts

Print the 11-part part set outlined in [printing/README.md](../printing/README.md). STL and CAD sources live under `hardware/printing/`.

## Consumables & Tools Checklist

| Item | Notes | Amazon |
| --- | --- | --- |
| Leaded solder (0.6–0.8 mm) | Easier flow for dense perfboard work | [link](https://www.amazon.com/s?k=63%2F37+solder+0.8mm) |
| Flux pen | Protects pads on the perfboard and PCB | [link](https://www.amazon.com/s?k=flux+pen) |
| Solder wick / pump | For rework on the OLED pins | [link](https://www.amazon.com/s?k=solder+wick) |
| Small flush cutters | Trim servo leads, perfboard traces, or supports | [link](https://www.amazon.com/s?k=flush+cutters) |
| Precision screwdriver set | Needed for self-tapping M2 hardware | [link](https://www.amazon.com/s?k=precision+screwdriver+set) |

## Power & Safety Notes

- Sesame needs at least 5 V at 3 A available at the rails. 
- **Lolin S2 Mini:** Can be powered via USB-C PD (5V/3A capable) for tethered operation, or via battery + buck converter.
- **Distro Board V2:** Supports both USB-C PD (5V/3A) for tethered operation AND battery + buck converter. Included in all Sesame Build Kits.
- **Distro Board V1 (Legacy):** Cannot run on tethered USB-C power due to design limitations. Must use battery + buck converter for operation.
- When battery powering either build, route the pack through the rocker switch and buck converter before it touches the rails, mirroring the schematic in [docs/wiring-guide/README.md](../../docs/wiring-guide/README.md).
- **Never cut the factory battery connector off the pack.** Instead, create adapter pigtails using XT30 or JST RCY leads so the pack remains chargeable.
- A 2× 10440 Li-ion + 2× AAA holder pack fits the stock battery cavity and works well with the existing power switch + buck converter.
- **Always remove and charge 10440 cells separately in a proper Li-ion charger.** Do not charge them while inside the AAA holder unless the holder explicitly supports safe Li-ion charging (most do not).

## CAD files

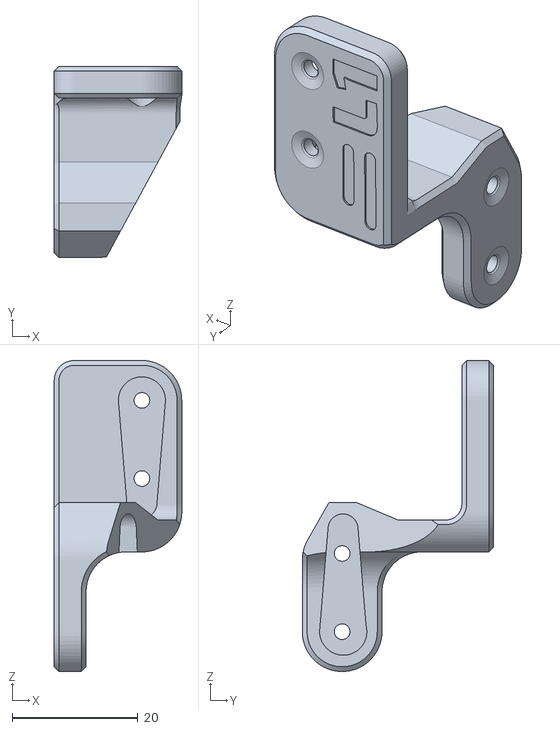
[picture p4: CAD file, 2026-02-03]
hardware/printing/stl/femurjoint-L1-v90.stl
20.3 x 30.5 x 49.5

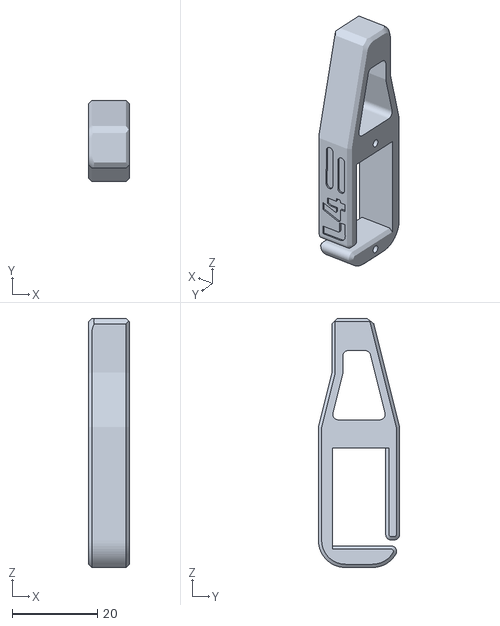
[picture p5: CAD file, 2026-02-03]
hardware/printing/stl/foot-joint-L4-v90.stl
9.53 x 19.0 x 58.4

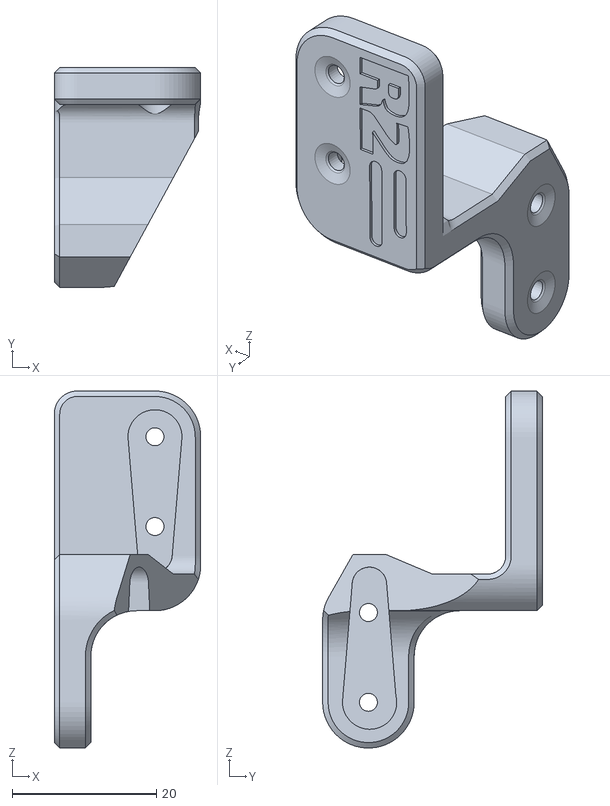
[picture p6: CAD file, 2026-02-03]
hardware/printing/stl/femurjoint-R2-v90.stl
20.3 x 30.5 x 49.5

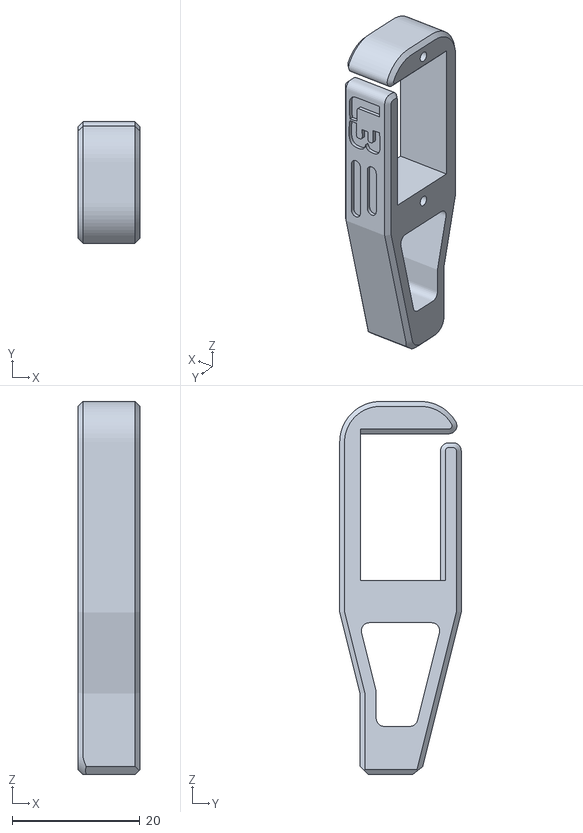
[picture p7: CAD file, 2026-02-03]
hardware/printing/stl/foot-joint-L3-v90.stl
9.70 x 19.0 x 58.4

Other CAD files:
hardware/printing/stl/foot-joint-R3-v90.stl
hardware/printing/stl/femurjoint-R1-v90.stl
hardware/printing/stl/foot-joint-R4-v90.stl
hardware/printing/stl/femurjoint-L2-v90.stl

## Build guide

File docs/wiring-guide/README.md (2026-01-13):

# Wiring Guide

Complete wiring guides for the Sesame Robot.

---

## Choosing a Wiring Approach

The project supports two wiring strategies that suit different build constraints:

- **S2 Mini / hand wiring:** Uses an ESP32-S2 Mini, loose headers, and point-to-point wiring. It is the lowest-cost option and easy to source, but it demands patience to keep the harness tidy and leaves less room for mistakes.
- **Sesame Distro Board / ESP32 DevKit:** Uses the custom distro PCB stacked on an ESP32-DevKitC-32E. It front-loads the work into soldering headers and the buck converter but dramatically simplifies routing, labeling, and maintenance once assembled.

Pick the approach that matches your component availability and comfort with managing wire bundles; the remainder of this guide dives into both workflows.

## How to wire the S2 Mini / Hand Wiring

The S2 Mini method is a traditional protoboard build. Consult the S2 Mini wiring diagram below while reading this section; it captures every motor, sensor, OLED, and button lead even if the photos only show a subset of the connections. Expect a high connection count, so plan wire lengths and colors before soldering to avoid confusion later.

S2 Mini wiring diagram

### Prep

1. **Secure and tin** all of the connections on the board before starting
2. To connect all the 3-pin headers together and to the board, first attach them to a small section of protoboard

proto-headers

### Building Power and Ground Rails

1. Solder one wire to one end of the pins, then guide it along and remove the insulation
2. Solder this exposed wire to every middle pin (this creates the **5V rail**)
3. Do the same for the ground lane (this creates the **ground rail**)

proto-power-rails

### Data Lines

You can now cut eight equal-length wires for data connections.

**Wire Recommendations:**
- **Data lines:** 30AWG silicone wire
- **Power and ground:** 22AWG silicone wire
- **Important:** Things will get super cluttered if you use large gauge wire

proto-data-lines

Alongside the eight motor data leads, the diagram also calls out the OLED connections that branch from the microcontroller.

### Packing Electronics

When packing electronics into the frame, it's difficult with the hand wiring setup because there are a lot of stray wires. My advice is to work slowly and methodically:

1. Group wires with similar destinations
2. Use zip ties and heat shrink tubing to make them as compact as possible
3. Consider connecting the power switch after finishing most other wiring, since it's attached to the top cover

wire-managment

### Safety and Testing

> [!CAUTION]
> Do not solder and de-solder connections with power connected!

**Before powering on:**
- Double check your power and ground lines before turning the robot on
- Make sure to cover any exposed wires as they can touch the pin headers and fry the ESP32 (especially when cramming the cover on)

> [!TIP]
> To make fishing out the wires for the OLED display easier, you can temporarily twist them together into a group and then guide them through the opening in the top cover.

---

## How to wire the Sesame Distro Board / ESP32-DevKitC-32E

### Overview

> [!IMPORTANT]  
> The distro board is mounted on top of the ESP32 devkit, like a hat. 

This option provides a cleaner, more organized wiring solution.
Consult the distro-board wiring diagram below for exact connection locations.

distro-board wiring diagram

### Component Installation

**Optional components** (you can solder directly to pads instead):
- 4-pin JST connector
- 2-pin screw terminal

**Pin header installation tip:** If you're having difficulties keeping the pin headers in place to solder, try placing them in a protoboard first, then transferring them over.

### Buck Converter Setup

A buck converter takes any voltage (5V-12V) and drops it to a stable 5V for the motors and ESP32.

**If using a battery:**
1. Make sure to solder the buck converter enable pads
2. The buck converter is **required** for battery operation

**Alternative power options:**
- If you're using a benchtop supply or have another regulated 5V source
- You can override the buck converter and take voltage directly from the screw terminal by soldering the override pads

### Battery Connection
> [!CAUTION]
> If your battery has an XT30 or JST RCY connector, don't cut it off and wire the battery directly to the distro board! This is unsafe and means you can't charge your battery anymore.

**Proper method:**
1. Get a female XT30 or JST RCY connector (matching your battery)
2. Wire it to two wires that lead to the power terminal
3. This allows you to safely connect and disconnect the battery

### Sourcing the Distro Board

The Sesame Distro Board is a custom PCB designed specifically for this project. It mounts on top of a ESP32-DevKitC-32E.

More information is avalible in the [PCB](../../hardware/pcb/README.md) section of the documentation.

---

## General Wiring Tips

- Work slowly and methodically
- Test connections before applying power
- Keep wire runs as short and neat as possible
- Label wires if helpful for troubleshooting
- Take photos during assembly for reference

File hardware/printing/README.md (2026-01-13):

# 3D Printing Guide

Sesame is designed to be printed in **PLA**. Most parts print without supports, but the body cover needs supports in targeted areas. Below is a quick reference for each component:

Note: There are 3 different top cover styles currently. Cat Enclosed, Enclosed, and Original Style.

## Recommended Settings
* **Material:** PLA / PLA+
* **Infill:** 8-10%
* **Wall Loops:** 2
* **Infill Pattern:** Honeycomb

## 3D Printed Components Support Guide

| Component | Supports Required | STL Link |
|---|---|---|
| Joint R1 | No | [femur-joint-R1-v71.stl](stl/femur-joint-R1-v71.stl) |
| Joint R2 | No | [femurjoint-R2--v71.stl](stl/femurjoint-R2--v71.stl) |
| Joint R3 | No | [foot-joint-R3-v71.stl](stl/foot-joint-R3-v71.stl) |
| Joint R4 | No | [foot-joint-R4-v71.stl](stl/foot-joint-R4-v71.stl) |
| Joint L1 | No | [femur-joint-L1-v71.stl](stl/femur-joint-L1-v71.stl) |
| Joint L2 | No | [femur-joint-L2-v71.stl](stl/femur-joint-L2-v71.stl) |
| Joint L3 | No | [foot-joint-L3-v71.stl](stl/foot-joint-L3-v71.stl) |
| Joint L4 | No | [foot-joint-L4-v71.stl](stl/foot-joint-L4-v71.stl) |
| Internal Frame  | No | [Interna-Frame-v71.stl](stl/Interna-Frame-v71.stl) |
| Bottom Cover | No | [Bottom-Cover-v71.stl](stl/Bottom-Cover-v71.stl) |
| Top Cover | Yes | [Top Covers](stl/top-covers/) |

### Top Cover Settings (Original Style)

Brim: Outer brim only
Support type: Normal (Manual)

Manual support locations:

topcover-supports2

This is what the part should look like sliced:

sliced-topcover

### Recommended Print Orientaiton for Joints:

Using the auto orientate tool will place these the correct way. 

sliced-topcover

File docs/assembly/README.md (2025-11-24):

# Assembly Instructions

Step-by-step assembly instructions for building the Sesame Robot.

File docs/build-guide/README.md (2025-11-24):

# Build Guide

Complete build guide for the Sesame Robot.

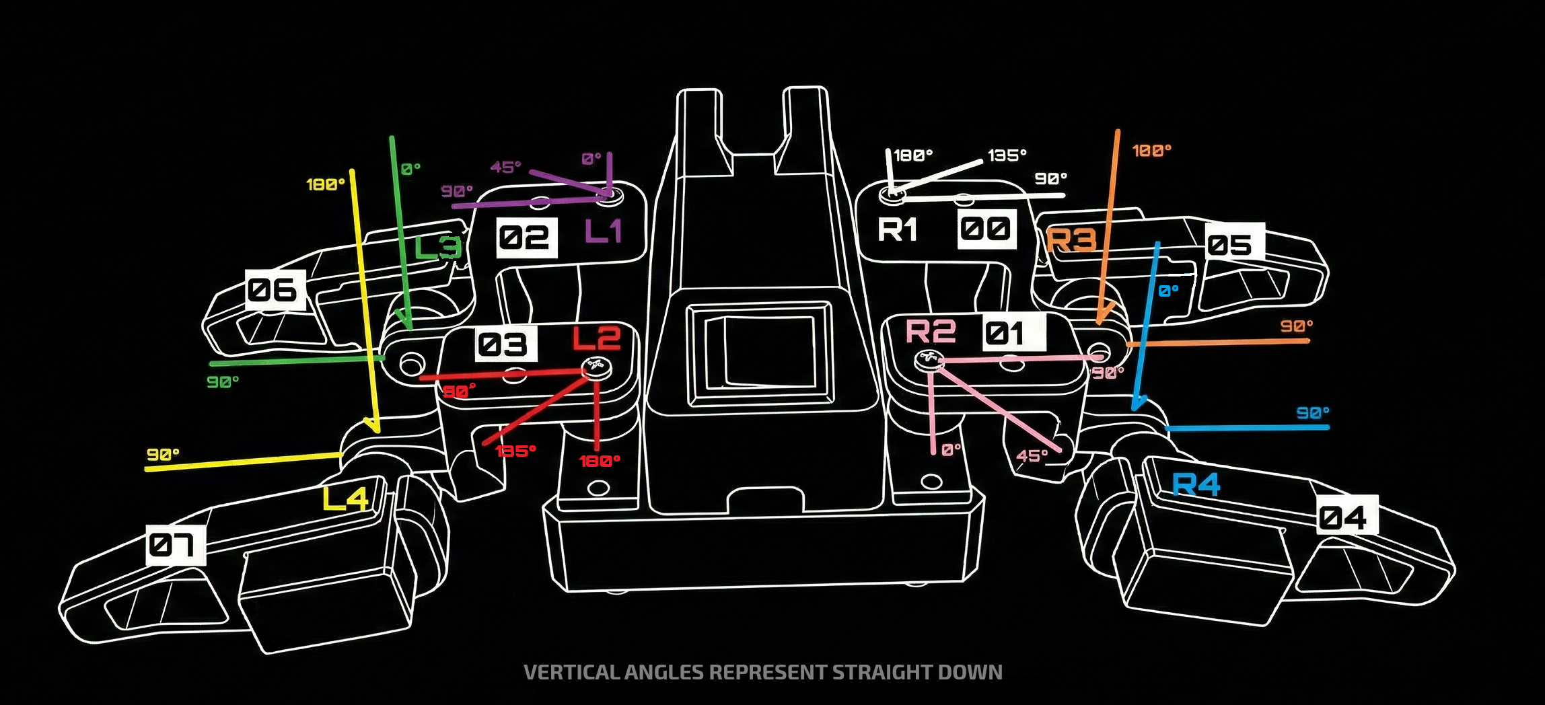
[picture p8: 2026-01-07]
software/sesame-studio/sesame-angle-guide.png

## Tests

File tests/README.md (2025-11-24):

# Tests

Test code and validation procedures for the Sesame Robot.

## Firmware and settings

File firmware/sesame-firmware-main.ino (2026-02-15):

#include <WiFi.h>
#include <WebServer.h>
#include <DNSServer.h>
#include <ESPmDNS.h>
#include <Wire.h>
#include <ESP32Servo.h>
#include <Adafruit_GFX.h>
#include <Adafruit_SSD1306.h>
#include "face-bitmaps.h"
#include "movement-sequences.h"
#include "captive-portal.h"

// --- Access Point Configuration ---
// This is the network the Robot will create
#define AP_SSID  "Sesame-Controller-BETA"
#define AP_PASS  "12345678" // Must be at least 8 characters

// --- Station Mode Configuration (Optional) ---
// Set these to connect to your home/office WiFi network
// Leave NETWORK_SSID empty to disable station mode
#define NETWORK_SSID ""  // Your WiFi network name
#define NETWORK_PASS ""  // Your WiFi password
#define ENABLE_NETWORK_MODE false  // Set to true to enable network connection attempts

#define SCREEN_WIDTH 128
#define SCREEN_HEIGHT 64
#define OLED_RESET -1
#define OLED_I2C_ADDR 0x3C

// I2C Pins for Distro Board V2
//#define I2C_SDA 8
//#define I2C_SCL 9

// I2C Pins for Distro Board
//#define I2C_SDA 21
//#define I2C_SCL 22

// I2C Pins for S2 Mini Board
#define I2C_SDA 33
#define I2C_SCL 35


// DNS Server for Captive Portal
DNSServer dnsServer;
const byte DNS_PORT = 53;

Adafruit_SSD1306 display(SCREEN_WIDTH, SCREEN_HEIGHT, &Wire, OLED_RESET);
WebServer server(80);

// Global state for animations
String currentCommand = "";
String currentFaceName = "default";
const unsigned char* const* currentFaceFrames = nullptr;
uint8_t currentFaceFrameCount = 0;
uint8_t currentFaceFrameIndex = 0;
unsigned long lastFaceFrameMs = 0;
int faceFps = 8;
FaceAnimMode currentFaceMode = FACE_ANIM_LOOP;
int8_t faceFrameDirection = 1;
bool faceAnimFinished = false;
int currentFaceFps = 0;
bool idleActive = false;
bool idleBlinkActive = false;
unsigned long nextIdleBlinkMs = 0;
uint8_t idleBlinkRepeatsLeft = 0;

// WiFi Info Scrolling
unsigned long lastInputTime = 0;
bool firstInputReceived = false;
bool showingWifiInfo = false;
int wifiScrollPos = 0;
unsigned long lastWifiScrollMs = 0;
String wifiInfoText = "";

// Network Mode
bool networkConnected = false;
IPAddress networkIP;
String deviceHostname = "sesame-robot";

// Servo Pins for Distro Board
// ======================================================================
// Pin numbers are coorisponding to the ESP32 GPIO pins and may differ based on which board you use.
// If you are using a different board, please adjust the servoPins array accordingly.
// ======================================================================
Servo servos[8];
// Sesame Distro Board V2 Pinout
//const int servoPins[8] = {4, 5, 6, 7, 15, 16, 17, 18};

// Sesame Distro Board Pinout
//const int servoPins[8] = {15, 2, 23, 19, 4, 16, 17, 18};

// Lolin S2 Mini Pinout
const int servoPins[8] = {1, 2, 4, 6, 8, 10, 13, 14};

// Subtrim values for each servo (offset in degrees)
int8_t servoSubtrim[8] = {0, 0, 0, 0, 0, 0, 0, 0};


// Animation constants
int frameDelay = 100;
int walkCycles = 10;
int motorCurrentDelay = 20; // ms delay between motor movements to prevent over-current

struct FaceEntry {
  const char* name;
  const unsigned char* const* frames;
  uint8_t maxFrames;
};

static const uint8_t MAX_FACE_FRAMES = 6;

#define MAKE_FACE_FRAMES(name) \
  const unsigned char* const face_##name##_frames[] = { \
    epd_bitmap_##name, epd_bitmap_##name##_1, epd_bitmap_##name##_2, \
    epd_bitmap_##name##_3, epd_bitmap_##name##_4, epd_bitmap_##name##_5 \
  };

#define X(name) MAKE_FACE_FRAMES(name)
FACE_LIST
#undef X
#undef MAKE_FACE_FRAMES

const FaceEntry faceEntries[] = {
#define X(name) { #name, face_##name##_frames, MAX_FACE_FRAMES },
  FACE_LIST
#undef X
  { "default", face_defualt_frames, MAX_FACE_FRAMES }
};

struct FaceFpsEntry {
  const char* name;
  uint8_t fps;
};

const FaceFpsEntry faceFpsEntries[] = {
  { "walk", 1 },
  { "rest", 1 },
  { "swim", 1 },
  { "dance", 1 },
  { "wave", 1 },
  { "point", 5 },
  { "stand", 1 },
  { "cute", 1 },
  { "pushup", 1 },
  { "freaky", 1 },
  { "bow", 1 },
  { "worm", 1 },
  { "shake", 1 },
  { "shrug", 1 },
  { "dead", 2 },
  { "crab", 1 },
  { "idle", 1 },
  { "idle_blink", 7 },
  { "default", 1 },
  // Conversational faces (manually controlled by Python - no auto-animation)
  { "happy", 1 },
  { "talk_happy", 1 },
  { "sad", 1 },
  { "talk_sad", 1 },
  { "angry", 1 },
  { "talk_angry", 1 },
  { "surprised", 1 },
  { "talk_surprised", 1 },
  { "sleepy", 1 },
  { "talk_sleepy", 1 },
  { "love", 1 },
  { "talk_love", 1 },
  { "excited", 1 },
  { "talk_excited", 1 },
  { "confused", 1 },
  { "talk_confused", 1 },
  { "thinking", 1 },
  { "talk_thinking", 1 },
};


// Prototypes
void setServoAngle(uint8_t channel, int angle);
void updateFaceBitmap(const unsigned char* bitmap);
void setFace(const String& faceName);
void setFaceMode(FaceAnimMode mode);
void setFaceWithMode(const String& faceName, FaceAnimMode mode);
void updateAnimatedFace();
void delayWithFace(unsigned long ms);
void enterIdle();
void exitIdle();
void updateIdleBlink();
int getFaceFpsForName(const String& faceName);
bool pressingCheck(String cmd, int ms);
void handleGetSettings();
void handleSetSettings();
void handleGetStatus();
void handleApiCommand();
void updateWifiInfoScroll();
void recordInput();

void handleRoot() {
  server.send(200, "text/html", index_html);
}

void handleCommandWeb() {
  // We send 200 OK immediately so the web browser doesn't hang waiting for animation to finish
  if (server.hasArg("pose")) {
    currentCommand = server.arg("pose");
    recordInput();
    exitIdle();
    server.send(200, "text/plain", "OK"); 
  } 
  else if (server.hasArg("go")) {
    currentCommand = server.arg("go");
    recordInput();
    exitIdle();
    server.send(200, "text/plain", "OK");
  } 
  else if (server.hasArg("stop")) {
    currentCommand = "";
    recordInput();
    server.send(200, "text/plain", "OK");
  }
  else if (server.hasArg("motor") && server.hasArg("value")) {
    int motorNum = server.arg("motor").toInt();
    int angle = server.arg("value").toInt();
    if (motorNum >= 1 && motorNum <= 8 && angle >= 0 && angle <= 180) {
      setServoAngle(motorNum - 1, angle); // Convert 1-based to 0-based index
      recordInput();
      server.send(200, "text/plain", "OK");
    } else {
      server.send(400, "text/plain", "Invalid motor or angle");
    }
  }
  else {
    server.send(400, "text/plain", "Bad Args");
  }
}

void handleGetSettings() {
  String json = "{";
  json += "\"frameDelay\":" + String(frameDelay) + ",";
  json += "\"walkCycles\":" + String(walkCycles) + ",";
  json += "\"motorCurrentDelay\":" + String(motorCurrentDelay) + ",";
  json += "\"faceFps\":" + String(faceFps);
  json += "}";
  server.send(200, "application/json", json);
}

void handleSetSettings() {
  if (server.hasArg("frameDelay")) frameDelay = server.arg("frameDelay").toInt();
  if (server.hasArg("walkCycles")) walkCycles = server.arg("walkCycles").toInt();
  if (server.hasArg("motorCurrentDelay")) motorCurrentDelay = server.arg("motorCurrentDelay").toInt();
  if (server.hasArg("faceFps")) faceFps = (int)max(1L, server.arg("faceFps").toInt());
  server.send(200, "text/plain", "OK");
}

// API endpoint for network clients to get robot status
void handleGetStatus() {
  String json = "{";
  json += "\"currentCommand\":\"" + currentCommand + "\",";
  json += "\"currentFace\":\"" + currentFaceName + "\",";
  json += "\"networkConnected\":" + String(networkConnected ? "true" : "false") + ",";
  json += "\"apIP\":\"" + WiFi.softAPIP().toString() + "\"";
  if (networkConnected) {
    json += ",\"networkIP\":\"" + networkIP.toString() + "\"";
  }
  json += "}";
  server.send(200, "application/json", json);
}

// API endpoint for network clients to send commands (JSON-based)
void handleApiCommand() {
  if (server.method() != HTTP_POST) {
    server.send(405, "application/json", "{\"error\":\"Method not allowed\"}");
    return;
  }
  
  String body = server.arg("plain");
  
  Serial.println("API Command received:");
  Serial.println(body);
  
  // Check for face-only command (no movement)
  int faceOnlyStart = body.indexOf("\"face\":\"");
  if (faceOnlyStart == -1) {
    faceOnlyStart = body.indexOf("\"face\": \"");
  }
  
  // If we have a face but no command field, it's face-only
  bool faceOnly = (faceOnlyStart > 0 && body.indexOf("\"command\":") == -1 && body.indexOf("\"command\": ") == -1);
  
  String command = "";
  String face = "";
  
  // Parse face
  if (faceOnlyStart > 0) {
    faceOnlyStart = body.indexOf("\"", faceOnlyStart + 6) + 1;
    int faceEnd = body.indexOf("\"", faceOnlyStart);
    if (faceEnd > faceOnlyStart) {
      face = body.substring(faceOnlyStart, faceEnd);
      Serial.print("Parsed face: ");
      Serial.println(face);
    }
  }
  
  // Parse command (if not face-only)
  if (!faceOnly) {
    int cmdStart = body.indexOf("\"command\":\"");
    if (cmdStart == -1) {
      cmdStart = body.indexOf("\"command\": \"");
    }
    
    if (cmdStart == -1) {
      Serial.println("Error: command field not found");
      server.send(400, "application/json", "{\"error\":\"Missing command field\"}");
      return;
    }
    
    cmdStart = body.indexOf("\"", cmdStart + 10) + 1;
    int cmdEnd = body.indexOf("\"", cmdStart);
    
    if (cmdEnd <= cmdStart) {
      Serial.println("Error: invalid command format");
      server.send(400, "application/json", "{\"error\":\"Invalid command format\"}");
      return;
    }
    
    command = body.substring(cmdStart, cmdEnd);
    Serial.print("Parsed command: ");
    Serial.println(command);
  }
  
  // Set face if provided
  if (face.length() > 0) {
    setFace(face);
  }
  
  // If face-only, just acknowledge
  if (faceOnly) {
    recordInput();
    server.send(200, "application/json", "{\"status\":\"ok\",\"message\":\"Face updated\"}");
    return;
  }
  
  // Execute command
  if (command == "stop") {
    currentCommand = "";
    recordInput();
    server.send(200, "application/json", "{\"status\":\"ok\",\"message\":\"Command stopped\"}");
  } else {
    currentCommand = command;
    recordInput();
    exitIdle();
    server.send(200, "application/json", "{\"status\":\"ok\",\"message\":\"Command executed\"}");
  }
}

void setup() {
  Serial.begin(115200);
  randomSeed(micros());
  
  // I2C Init for ESP32
  Wire.begin(I2C_SDA, I2C_SCL);

  // OLED Init
  if (!display.begin(SSD1306_SWITCHCAPVCC, OLED_I2C_ADDR)) {
    Serial.println(F("SSD1306 allocation failed."));
    while (1);
  }
  
  display.clearDisplay();
  display.setTextColor(SSD1306_WHITE);
  display.setTextSize(1);
  display.setCursor(0,0);
  display.println(F("Setting up WiFi..."));
  display.display();

  // --- WIFI CONFIGURATION ---
  // Try to connect to network first if configured
  if (ENABLE_NETWORK_MODE && String(NETWORK_SSID).length() > 0) {
    Serial.println("Attempting to connect to network: " + String(NETWORK_SSID));
    WiFi.mode(WIFI_AP_STA); // Enable both AP and Station modes
    WiFi.setHostname(deviceHostname.c_str());
    WiFi.begin(NETWORK_SSID, NETWORK_PASS);
    
    // Wait up to 10 seconds for connection
    int attempts = 0;
    while (WiFi.status() != WL_CONNECTED && attempts < 20) {
      delay(500);
      Serial.print(".");
      attempts++;
    }
    
    if (WiFi.status() == WL_CONNECTED) {
      networkConnected = true;
      networkIP = WiFi.localIP();
      Serial.println();
      Serial.print("Connected to network! IP: ");
      Serial.println(networkIP);
    } else {
      Serial.println();
      Serial.println("Failed to connect to network. Running in AP-only mode.");
      WiFi.mode(WIFI_AP); // Fall back to AP-only
    }
  } else {
    WiFi.mode(WIFI_AP);
    Serial.println("Network mode disabled. Running in AP-only mode.");
  }
  
  // --- ACCESS POINT CONFIGURATION ---
  WiFi.softAP(AP_SSID, AP_PASS);
  IPAddress myIP = WiFi.softAPIP();
  
  Serial.print("AP Created. IP: ");
  Serial.println(myIP);

  // Build WiFi info text for scrolling
  if (networkConnected) {
    wifiInfoText = "AP: " + String(AP_SSID) + " (" + myIP.toString() + ")  |  Network: " + String(NETWORK_SSID) + " (" + networkIP.toString() + ") or " + deviceHostname + ".local  |  ";
  } else {
    wifiInfoText = "Connect to WiFi: " + String(AP_SSID) + "  |  Pass: " + String(AP_PASS) + "  |  IP: " + myIP.toString() + "  |  Captive Portal will auto-open!  |  ";
  }
  
  // Initialize input tracking
  lastInputTime = millis();
  firstInputReceived = false;
  showingWifiInfo = false;

  // Start mDNS responder for local network discovery
  if (MDNS.begin(deviceHostname.c_str())) {
    Serial.println("mDNS responder started");
    Serial.print("Access controller at: http://");
    Serial.print(deviceHostname);
    Serial.println(".local");
    MDNS.addService("http", "tcp", 80);
  } else {
    Serial.println("Error setting up mDNS responder!");
  }

  // Start DNS Server for Captive Portal
  // This redirects ALL domain requests to the ESP32's IP
  dnsServer.start(DNS_PORT, "*", myIP);

  // Web Server Routes
  server.on("/", handleRoot);
  server.on("/cmd", handleCommandWeb);
  server.on("/getSettings", handleGetSettings);
  server.on("/setSettings", handleSetSettings);
  
  // API endpoints for network communication
  server.on("/api/status", handleGetStatus);
  server.on("/api/command", handleApiCommand);
  
  // Catch-all route for captive portal
  // This ensures any URL redirects to the controller page
  server.onNotFound(handleRoot);
  
  server.begin();

  // PWM Init
  ESP32PWM::allocateTimer(0);
  ESP32PWM::allocateTimer(1);
  ESP32PWM::allocateTimer(2);
  ESP32PWM::allocateTimer(3);
  
  for (int i = 0; i < 8; i++) {
    servos[i].setPeriodHertz(50);
    // Map 0-180 to approx 732-2929us
    servos[i].attach(servoPins[i], 732, 2929);
  }
  delay(10);
  
  // Show rest face on startup without moving motors
  setFace("rest");
  
  Serial.println(F("HTTP server & Captive Portal started."));
}

void loop() {
  // Process DNS requests for captive portal
  dnsServer.processNextRequest();
  
  server.handleClient();
  updateAnimatedFace();
  updateIdleBlink();
  updateWifiInfoScroll();

  if (currentCommand != "") {
    String cmd = currentCommand;
    if (cmd == "forward") runWalkPose();
    else if (cmd == "backward") runWalkBackward();
    else if (cmd == "left") runTurnLeft();
    else if (cmd == "right") runTurnRight();
    else if (cmd == "rest") { runRestPose(); if (currentCommand == "rest") currentCommand = ""; }
    else if (cmd == "stand") { runStandPose(1); if (currentCommand == "stand") currentCommand = ""; }
    else if (cmd == "wave") runWavePose();
    else if (cmd == "dance") runDancePose();
    else if (cmd == "swim") runSwimPose();
    else if (cmd == "point") runPointPose();
    else if (cmd == "pushup") runPushupPose();
    else if (cmd == "bow") runBowPose();
    else if (cmd == "cute") runCutePose();
    else if (cmd == "freaky") runFreakyPose();
    else if (cmd == "worm") runWormPose();
    else if (cmd == "shake") runShakePose();
    else if (cmd == "shrug") runShrugPose();
    else if (cmd == "dead") runDeadPose();
    else if (cmd == "crab") runCrabPose();
  }
  
  // Serial CLI for debugging (can be used to diagnose servo position issues and wiring)
  if (Serial.available()) {
    static char command_buffer[32];
    static byte buffer_pos = 0;
    char c = Serial.read();
    if (c == '\n' || c == '\r') {
      if (buffer_pos > 0) {
        command_buffer[buffer_pos] = '\0';
        int motorNum, angle;
        recordInput();
        if(strcmp(command_buffer, "run walk") == 0 || strcmp(command_buffer, "rn wf") == 0) { currentCommand = "forward"; runWalkPose(); currentCommand = ""; }
        else if(strcmp(command_buffer, "rn wb") == 0) { currentCommand = "backward"; runWalkBackward(); currentCommand = ""; }
        else if(strcmp(command_buffer, "rn tl") == 0) { currentCommand = "left"; runTurnLeft(); currentCommand = ""; }
        else if(strcmp(command_buffer, "rn tr") == 0) { currentCommand = "right"; runTurnRight(); currentCommand = ""; }
        else if(strcmp(command_buffer, "run rest") == 0 || strcmp(command_buffer, "rn rs") == 0) runRestPose();
        else if(strcmp(command_buffer, "run stand") == 0 || strcmp(command_buffer, "rn st") == 0) runStandPose(1);
        else if(strcmp(command_buffer, "rn wv") == 0) { currentCommand = "wave"; runWavePose(); }
        else if(strcmp(command_buffer, "rn dn") == 0) { currentCommand = "dance"; runDancePose(); }
        else if(strcmp(command_buffer, "rn sw") == 0) { currentCommand = "swim"; runSwimPose(); }
        else if(strcmp(command_buffer, "rn pt") == 0) { currentCommand = "point"; runPointPose(); }
        else if(strcmp(command_buffer, "rn pu") == 0) { currentCommand = "pushup"; runPushupPose(); }
        else if(strcmp(command_buffer, "rn bw") == 0) { currentCommand = "bow"; runBowPose(); }
        else if(strcmp(command_buffer, "rn ct") == 0) { currentCommand = "cute"; runCutePose(); }
        else if(strcmp(command_buffer, "rn fk") == 0) { currentCommand = "freaky"; runFreakyPose(); }
        else if(strcmp(command_buffer, "rn wm") == 0) { currentCommand = "worm"; runWormPose(); }
        else if(strcmp(command_buffer, "rn sk") == 0) { currentCommand = "shake"; runShakePose(); }
        else if(strcmp(command_buffer, "rn sg") == 0) { currentCommand = "shrug"; runShrugPose(); }
        else if(strcmp(command_buffer, "rn dd") == 0) { currentCommand = "dead"; runDeadPose(); }
        else if(strcmp(command_buffer, "rn cb") == 0) { currentCommand = "crab"; runCrabPose(); }
        else if (strcmp(command_buffer, "subtrim") == 0 || strcmp(command_buffer, "st") == 0) {
          Serial.println("Subtrim values:");
          for (int i = 0; i < 8; i++) {
            Serial.print("Motor "); Serial.print(i); Serial.print(": ");
            if (servoSubtrim[i] >= 0) Serial.print("+");
            Serial.println(servoSubtrim[i]);
          }
        }
        else if (strcmp(command_buffer, "subtrim save") == 0 || strcmp(command_buffer, "st save") == 0) {
          Serial.println("Copy and paste this into your code:");
          Serial.print("int8_t servoSubtrim[8] = {");
          for (int i = 0; i < 8; i++) {
            Serial.print(servoSubtrim[i]);
            if (i < 7) Serial.print(", ");
          }
          Serial.println("};");
        }
        else if (strncmp(command_buffer, "subtrim reset", 13) == 0 || strncmp(command_buffer, "st reset", 8) == 0) {
          for (int i = 0; i < 8; i++) servoSubtrim[i] = 0;
          Serial.println("All subtrim values reset to 0");
        }
        else if (strncmp(command_buffer, "subtrim ", 8) == 0 || strncmp(command_buffer, "st ", 3) == 0) {
          const char* params = (command_buffer[1] == 't') ? command_buffer + 3 : command_buffer + 8;
          int trimMotor, trimValue;
          if (sscanf(params, "%d %d", &trimMotor, &trimValue) == 2) {
            if (trimMotor >= 0 && trimMotor < 8) {
              if (trimValue >= -90 && trimValue <= 90) {
                servoSubtrim[trimMotor] = trimValue;
                Serial.print("Motor "); Serial.print(trimMotor); Serial.print(" subtrim set to ");
                if (trimValue >= 0) Serial.print("+");
                Serial.println(trimValue);
              } else {
                Serial.println("Subtrim value must be between -90 and +90");
              }
            } else {
              Serial.println("Invalid motor number (0-7)");
            }
          }
        }
        else if (strncmp(command_buffer, "all ", 4) == 0) {
             if (sscanf(command_buffer + 4, "%d", &angle) == 1) {
                 for (int i = 0; i < 8; i++) setServoAngle(i, angle);
                 Serial.print("All servos set to "); Serial.println(angle);
             }
        }
        else if (sscanf(command_buffer, "%d %d", &motorNum, &angle) == 2) {
             if (motorNum >= 0 && motorNum < 8) {
                 setServoAngle(motorNum, angle);
                 Serial.print("Servo "); Serial.print(motorNum); Serial.print(" set to "); Serial.println(angle);
             } else {
                 Serial.println("Invalid motor number (0-7)");
             }
        }
        buffer_pos = 0;
      }
    } else if (buffer_pos < sizeof(command_buffer) - 1) {
      command_buffer[buffer_pos++] = c;
    }
  }
}

// Function to update the robot's face
void updateFaceBitmap(const unsigned char* bitmap) {
  display.clearDisplay();
  display.drawBitmap(0, 0, bitmap, 128, 64, SSD1306_WHITE);
  display.display();
}

uint8_t countFrames(const unsigned char* const* frames, uint8_t maxFrames) {
  if (frames == nullptr || frames[0] == nullptr) return 0;
  uint8_t count = 0;
  for (uint8_t i = 0; i < maxFrames; i++) {
    if (frames[i] == nullptr) break;
    count++;
  }
  return count;
}

void setFace(const String& faceName) {
  if (faceName == currentFaceName && currentFaceFrames != nullptr) return;

  currentFaceName = faceName;
  currentFaceFrameIndex = 0;
  lastFaceFrameMs = 0;
  faceFrameDirection = 1;
  faceAnimFinished = false;
  currentFaceFps = getFaceFpsForName(faceName);

  currentFaceFrames = face_defualt_frames;
  currentFaceFrameCount = countFrames(face_defualt_frames, MAX_FACE_FRAMES);

  for (size_t i = 0; i < (sizeof(faceEntries) / sizeof(faceEntries[0])); i++) {
    if (faceName.equalsIgnoreCase(faceEntries[i].name)) {
      currentFaceFrames = faceEntries[i].frames;
      currentFaceFrameCount = countFrames(faceEntries[i].frames, faceEntries[i].maxFrames);
      break;
    }
  }

  if (currentFaceFrameCount == 0) {
    currentFaceFrames = face_defualt_frames;
    currentFaceFrameCount = countFrames(face_defualt_frames, MAX_FACE_FRAMES);
    currentFaceName = "default";
    currentFaceFps = getFaceFpsForName(currentFaceName);
  }

  if (currentFaceFrameCount > 0 && currentFaceFrames[0] != nullptr) {
    updateFaceBitmap(currentFaceFrames[0]);
  }
}

void setFaceMode(FaceAnimMode mode) {
  currentFaceMode = mode;
  faceFrameDirection = 1;
  faceAnimFinished = false;
}
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

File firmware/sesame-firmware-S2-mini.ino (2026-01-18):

#include <WiFi.h>
#include <WebServer.h>
#include <DNSServer.h>
#include <Wire.h>
#include <ESP32Servo.h>
#include <Adafruit_GFX.h>
#include <Adafruit_SSD1306.h>

// --- Access Point Configuration ---
// This is the network the Robot will create
#define AP_SSID  "Sesame-Controller"
#define AP_PASS  "12345678" // Must be at least 8 characters

#define SCREEN_WIDTH 128
#define SCREEN_HEIGHT 64
#define OLED_RESET -1
#define OLED_I2C_ADDR 0x3C

// I2C Pins for S2 Mini Board
#define I2C_SDA 33
#define I2C_SCL 35

// DNS Server for Captive Portal
DNSServer dnsServer;
const byte DNS_PORT = 53;

Adafruit_SSD1306 display(SCREEN_WIDTH, SCREEN_HEIGHT, &Wire, OLED_RESET);
WebServer server(80);

// Global state for animations
String currentCommand = "";

// ======================================================================
// Pin numbers are coorisponding to the ESP32 GPIO pins and may differ based on which board you use.
// If you are using a different board, please adjust the servoPins array accordingly.
// ======================================================================
Servo servos[8];
// Lolin S2 Mini Pinout
const int servoPins[8] = {1, 2, 4, 6, 8, 10, 13, 14};

// Animation constants
int frameDelay = 100;
int walkCycles = 10;
int motorCurrentDelay = 20; // ms delay between motor movements to prevent over-current

// ======================================================================
// --- FACE BITMAPS ---
// Bitmaps for the faces are stored here, can be generated with image2cpp
// ======================================================================
// 'walk', 128x64px
const unsigned char epd_bitmap_walk [] PROGMEM = {
	0x00, 0x00, 0x00, 0x00, 0x00, 0x00, 0x00, 0x00, 0x00, 0x00, 0x00, 0x00, 0x00, 0x00, 0x00, 0x00, 
	0x00, 0x00, 0x00, 0x00, 0x00, 0x00, 0x00, 0x00, 0x00, 0x00, 0x00, 0x00, 0x00, 0x00, 0x00, 0x00, 
	0x00, 0x00, 0x00, 0x00, 0x00, 0x00, 0x00, 0x00, 0x00, 0x00, 0x00, 0x00, 0x00, 0x00, 0x00, 0x00, 
	0x00, 0x00, 0x00, 0x00, 0x00, 0x00, 0x00, 0x00, 0x00, 0x00, 0x00, 0x00, 0x00, 0x00, 0x00, 0x00, 
	0x00, 0x00, 0x00, 0x00, 0x00, 0x00, 0x00, 0x00, 0x00, 0x00, 0x00, 0x00, 0x00, 0x00, 0x00, 0x00, 
	0x00, 0x00, 0x00, 0x00, 0x00, 0x00, 0x00, 0x00, 0x00, 0x00, 0x00, 0x00, 0x00, 0x00, 0x00, 0x00, 
	0x00, 0x00, 0x00, 0x00, 0x00, 0x00, 0x00, 0x00, 0x00, 0x00, 0x00, 0x00, 0x00, 0x00, 0x00, 0x00, 
	0x00, 0x00, 0x00, 0x00, 0x00, 0x00, 0x00, 0x00, 0x00, 0x00, 0x00, 0x00, 0x00, 0x00, 0x00, 0x00, 
	0x00, 0x00, 0x00, 0x00, 0x00, 0x00, 0x00, 0x00, 0x00, 0x00, 0x00, 0x00, 0x00, 0x00, 0x00, 0x00, 
	0x00, 0x00, 0x00, 0x00, 0x00, 0x00, 0x00, 0x00, 0x00, 0x00, 0x00, 0x00, 0x00, 0x00, 0x00, 0x00, 
	0x00, 0x00, 0x00, 0x00, 0x00, 0x00, 0x00, 0x00, 0x00, 0x00, 0x00, 0x00, 0x00, 0x00, 0x00, 0x00, 
	0x00, 0x00, 0x00, 0x00, 0x00, 0x00, 0x00, 0x00, 0x00, 0x00, 0x00, 0x00, 0x00, 0x00, 0x00, 0x00, 
	0x00, 0x00, 0x00, 0x00, 0x00, 0x00, 0x00, 0x00, 0x00, 0x00, 0x00, 0x00, 0x00, 0x00, 0x00, 0x00, 
	0x00, 0x00, 0x00, 0x00, 0x00, 0x00, 0x00, 0x00, 0x00, 0x00, 0x00, 0x00, 0x00, 0x00, 0x00, 0x00, 
	0x00, 0x00, 0x00, 0x00, 0x00, 0x00, 0x00, 0x00, 0x00, 0x00, 0x00, 0x00, 0x00, 0x00, 0x00, 0x00, 
	0x00, 0x00, 0x00, 0x00, 0x00, 0x00, 0x00, 0x00, 0x00, 0x00, 0x00, 0x00, 0x00, 0x00, 0x00, 0x00, 
	0x00, 0x00, 0x00, 0x00, 0x00, 0x00, 0x00, 0x00, 0x00, 0x00, 0x00, 0x00, 0x00, 0x00, 0x00, 0x00, 
	0x00, 0x00, 0x00, 0x00, 0x3f, 0x00, 0x00, 0x00, 0x00, 0x01, 0xf8, 0x00, 0x00, 0x00, 0x00, 0x00, 
	0x00, 0x01, 0xf0, 0x00, 0x1f, 0x80, 0x00, 0x00, 0x00, 0x03, 0xf0, 0x00, 0x00, 0x3c, 0x00, 0x00, 
	0x00, 0x01, 0xe0, 0x00, 0x0f, 0x80, 0x00, 0x00, 0x00, 0x07, 0xc0, 0x00, 0x00, 0x1e, 0x00, 0x00, 
	0x00, 0x03, 0xe0, 0x00, 0x07, 0xc0, 0x00, 0x00, 0x00, 0x0f, 0x80, 0x00, 0x00, 0x1f, 0x00, 0x00, 
	0x00, 0x03, 0xc0, 0x00, 0x01, 0xe0, 0x00, 0x00, 0x00, 0x0f, 0x00, 0x00, 0x00, 0x0f, 0x00, 0x00, 
	0x00, 0x07, 0xc0, 0x00, 0x00, 0x00, 0x00, 0x00, 0x00, 0x00, 0x00, 0x00, 0x00, 0x0f, 0x80, 0x00, 
	0x00, 0x07, 0x80, 0x00, 0x00, 0x00, 0x00, 0x00, 0x00, 0x00, 0x00, 0x00, 0x00, 0x07, 0x80, 0x00, 
	0x00, 0x0f, 0x80, 0x00, 0x00, 0x7c, 0x00, 0x00, 0x00, 0x00, 0xf8, 0x00, 0x00, 0x07, 0xc0, 0x00, 
	0x00, 0x0f, 0x80, 0x00, 0x00, 0xfe, 0x00, 0x00, 0x00, 0x01, 0xfc, 0x00, 0x00, 0x07, 0xc0, 0x00, 
	0x00, 0x0f, 0x00, 0x00, 0x01, 0xff, 0x00, 0x00, 0x00, 0x03, 0xfe, 0x00, 0x00, 0x03, 0xc0, 0x00, 
	0x00, 0x0f, 0x00, 0x00, 0x01, 0xff, 0x00, 0x00, 0x00, 0x03, 0xfe, 0x00, 0x00, 0x03, 0xc0, 0x00, 
	0x00, 0x1f, 0x00, 0x00, 0x01, 0xff, 0x00, 0x00, 0x00, 0x03, 0xfe, 0x00, 0x00, 0x03, 0xc0, 0x00, 
	0x00, 0x1f, 0x00, 0x00, 0x01, 0xff, 0x00, 0x00, 0x00, 0x03, 0xfe, 0x00, 0x00, 0x03, 0xe0, 0x00, 
	0x00, 0x1f, 0x00, 0x00, 0x01, 0xff, 0x00, 0x1f, 0xe0, 0x03, 0xfe, 0x00, 0x00, 0x03, 0xe0, 0x00, 
	0x00, 0x1f, 0x00, 0x00, 0x01, 0xff, 0x00, 0x1f, 0xe0, 0x03, 0xfe, 0x00, 0x00, 0x03, 0xe0, 0x00, 
	0x00, 0x1f, 0x00, 0x00, 0x00, 0xfe, 0x00, 0x1f, 0xe0, 0x01, 0xfc, 0x00, 0x00, 0x03, 0xe0, 0x00, 
	0x00, 0x1f, 0x00, 0x00, 0x00, 0x7c, 0x00, 0x1f, 0xe0, 0x00, 0xf8, 0x00, 0x00, 0x03, 0xe0, 0x00, 
	0x00, 0x1f, 0x00, 0x00, 0x00, 0x00, 0x00, 0x00, 0x00, 0x00, 0x00, 0x00, 0x00, 0x03, 0xe0, 0x00, 
	0x00, 0x1f, 0x00, 0x00, 0x00, 0x00, 0x00, 0x00, 0x00, 0x00, 0x00, 0x00, 0x00, 0x03, 0xe0, 0x00, 
	0x00, 0x1f, 0x00, 0x00, 0x00, 0x00, 0x00, 0x00, 0x00, 0x00, 0x00, 0x00, 0x00, 0x03, 0xc0, 0x00, 
	0x00, 0x0f, 0x00, 0x00, 0x00, 0x00, 0x00, 0x00, 0x00, 0x00, 0x00, 0x00, 0x00, 0x03, 0xc0, 0x00, 
	0x00, 0x0f, 0x80, 0x00, 0x00, 0x00, 0x00, 0x00, 0x00, 0x00, 0x00, 0x00, 0x00, 0x07, 0xc0, 0x00, 
	0x00, 0x0f, 0x80, 0x00, 0x00, 0x00, 0x00, 0x00, 0x00, 0x00, 0x00, 0x00, 0x00, 0x07, 0xc0, 0x00, 
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

};
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

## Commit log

2026-01-07 Add Sesame Studio animation tool
    Introduces Sesame Studio, a Python-based GUI for composing robot animations and generating C++ code for the Sesame Robot. Includes documentation and initial implementation with servo input, frame seq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
2026-01-13 Update hardware and wiring docs with improved images and links
    Replaced markdown image syntax with HTML <img> tags for better control over image display in wiring and PCB guides. Updated BOM PCB link to reference local documentation. Revised printing guide to include STL file links and note multiple top cover styles. Minor grammar and formatting improvements throughout hardware documentation.
2026-01-13 Added CAD version 73 Files
    Added f3z archive and step archive files for base sesame full design.
2026-01-15 Fix little typo in PCB README to render image
    "L" should be "l" to match the name of the image file.
2026-01-18 Revamp forward and reverse walk cycle + Bitmaps
    Replaced placeholder face bitmap arrays with actual 128x64px bitmap data for various face expressions in sesame-firmware-S2-mini.ino. Also updated comments for I2C and servo pin definitions to be more generic for the S2 Mini board.
    Revamped walk cycle for consistency, fixed reverse walk cycle for going backwards.
    [sesame-firmware-S2-mini.ino, sesame-firmware-distroboard.ino]
2026-02-03 Update joints to v90
    Updated all joints to design version 90. Debossed text and details are now significantly larger to improve print tolerance. Resolves Issue #20
    [femur-joint-L1-v71.stl, femur-joint-L2-v71.stl, femur-joint-R1-v71.stl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]
2026-02-03 Revamp captive portal UI and controls
    Overhauled the captive-portal HTML/CSS/JS to modernize the UI and add features: updated page title and responsive layout, new visual theme vars and polished button/section styles, and a desktop-friendly column layout. Added a command queue (max 3) with status indicator and queue management to throttle commands, plus motor locking during animations. Introduced a Manual Motor Control panel with 8 sliders and lock indicator, expanded Settings with grouped sections, motor speed and debugMode options, and theme color selection (persisted to localStorage). Gamepad support and polling were implemented with button/axis bindings and UI connection state. Adjusted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
2026-02-15 Add 1000 µF electrolytic capacitor to BOM #33
    Add a 1000 µF electrolytic capacitor entry to hardware/bom/README.md. The capacitor is recommended to smooth the buck converter output (10V+ rating advised) and is included with a reference link for 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

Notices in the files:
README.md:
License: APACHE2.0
